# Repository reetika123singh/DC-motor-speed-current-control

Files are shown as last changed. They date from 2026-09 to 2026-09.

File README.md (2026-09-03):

# DRV8833 Dual H-Bridge Motor Driver — PCB and Cascade Speed & Current Control

A DC motor drive system built around the DRV8833 dual H-bridge driver, with a custom KiCad PCB and a Simulink/Simscape simulation of a cascade control architecture for precise speed regulation.

## Key Specifications

| Parameter | Value |
|---|---|
| Supply Voltage | 12 V |
| PWM Switching Frequency | 10 kHz |
| Speed Setpoint (simulated) | 1600 RPM |
| Current Limit (inner loop saturation) | 0 – 1.6 A |
| Control Architecture | Cascade: outer speed loop → inner current loop |

## Control Architecture

The system uses a **cascade (dual-loop) control structure**, which regulates motor speed while keeping motor current within a safe limit:

1. **Outer speed loop:**  PI controller (P = 0.002, I = 0.02) compares the RPM setpoint against measured speed and outputs a current command.
2. **Saturation stage:** The current command is clamped to 0–1.6 A, acting as a current limiter between the two loops.
3. **Inner current loop:** PI controller (P = 0.5, I = 5) compares the (limited) current command against sensed motor current and drives the H-Bridge PWM input.
4. **Plant:** An averaged H-Bridge model (12V, 10kHz) driving a Simscape DC Motor model (Ra = 2Ω, La = 1mH, Kv = 0.0072 V/rpm, J = 1e-5 kg·m²), with feedback from a Current Sensor (inner loop) and an Ideal Rotational Motion Sensor (outer loop, converted from rad/s to RPM).

## Repository Structure

- `Motor driver DRV8833.kicad_pro` (+ associated schematic/PCB files) — KiCad project for the DRV8833 driver board, including power rail decoupling and charge pump circuitry.
- `Motor_speed_control.slx` — Simulink/Simscape model implementing the cascade control loop described above.

## How to Run the Simulation

1. Open MATLAB and load `Motor_speed_control.slx` in Simulink.
2. Run the simulation to observe the motor speed settling toward the 1600 RPM setpoint and the current staying within the 0–1.6 A limit.
3. View the Scope block for speed and current response over time.

## PCB




## Results




1. **Settling time:** 0.12s
2. **Steady-state speed error:** +100 RPM
3. **Peak current during startup:** 1.4 A

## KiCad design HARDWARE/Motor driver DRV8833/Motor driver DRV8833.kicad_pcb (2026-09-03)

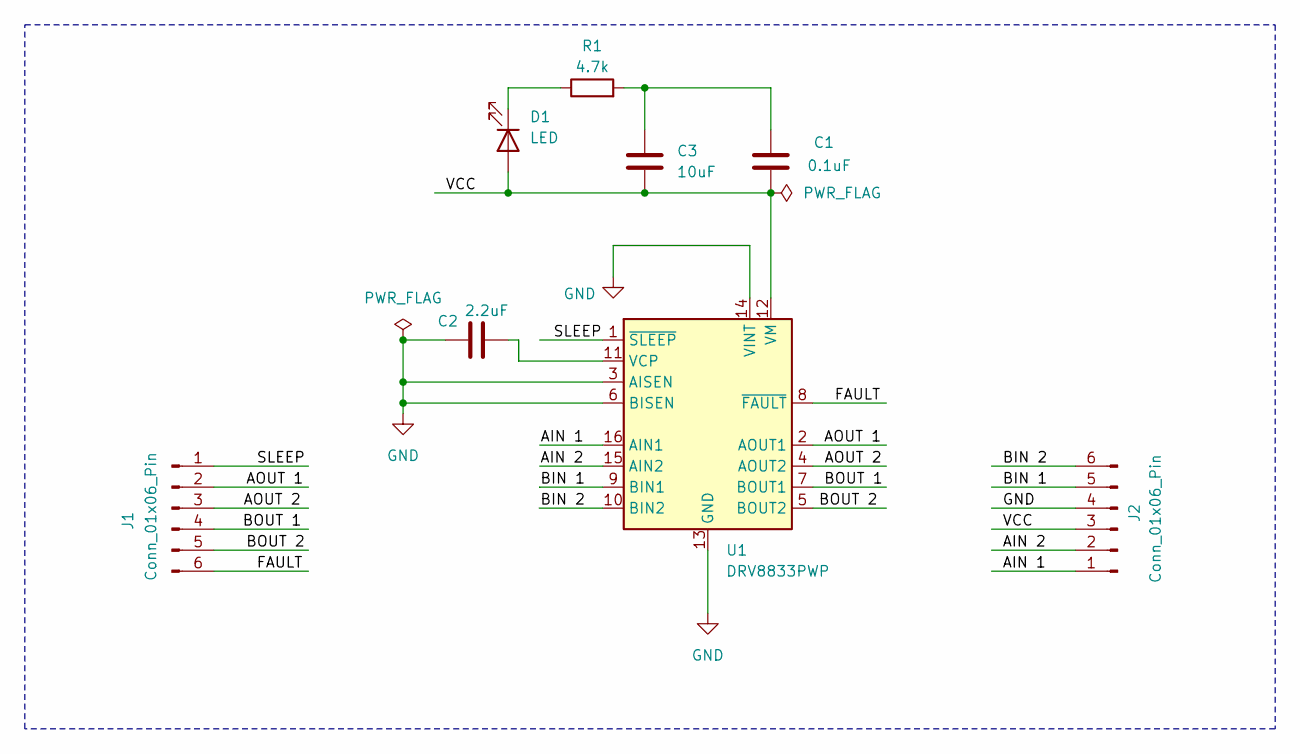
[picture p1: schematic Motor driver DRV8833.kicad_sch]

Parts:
C1: 0.1uF; C_0805_2012Metric
C2: 2.2uF; C_0805_2012Metric
C3: 10uF; CP_EIA-6032-20_AVX-F
D1: LED; LED_0805_2012Metric
J1, J2: Conn_01x06_Pin; PinHeader_1x06_P2.54mm_Vertical
R1: 4.7k; R_0805_2012Metric
U1: DRV8833PWP; HTSSOP-16-1EP_4.4x5mm_P0.65mm_EP3.4x5mm_Mask2.46x2.31mm_The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

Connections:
/AIN 1: J2.1, U1.16 (AIN1)
/AIN 2: J2.2, U1.15 (AIN2)
/AOUT 1: J1.2, U1.2 (AOUT1)
/AOUT 2: J1.3, U1.4 (AOUT2)
/BIN 1: J2.5, U1.9 (BIN1)
/BIN 2: J2.6, U1.10 (BIN2)
/BOUT 1: J1.4, U1.7 (BOUT1)
/BOUT 2: J1.5, U1.5 (BOUT2)
/FAULT: J1.6, U1.8 (~FAULT)
/SLEEP: J1.1, U1.1 (~SLEEP)
/VCC: C1.2, C3.2, D1.2 (A), J2.3, U1.12 (VM)
GND: C2.1, J2.4, U1.3 (AISEN), U1.6 (BISEN), U1.13 (GND), U1.14 (VINT), U1.17 (GND)
unnamed: C1.1, C3.1, R1.2
unnamed: D1.1 (K), R1.1
unnamed: C2.2, U1.11 (VCP)

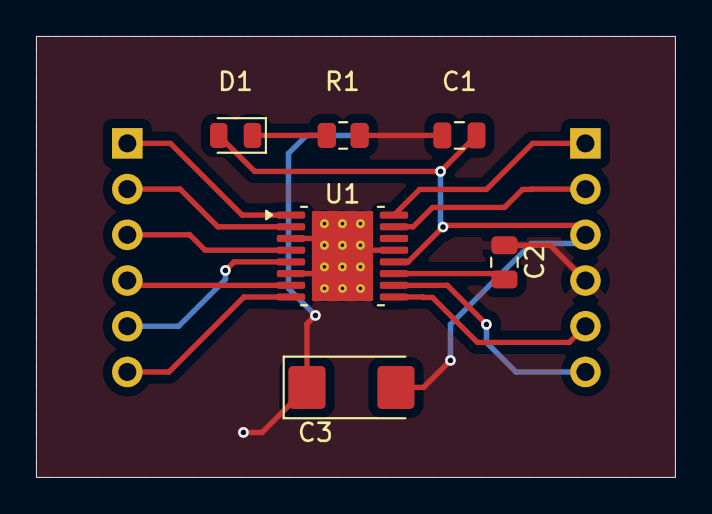
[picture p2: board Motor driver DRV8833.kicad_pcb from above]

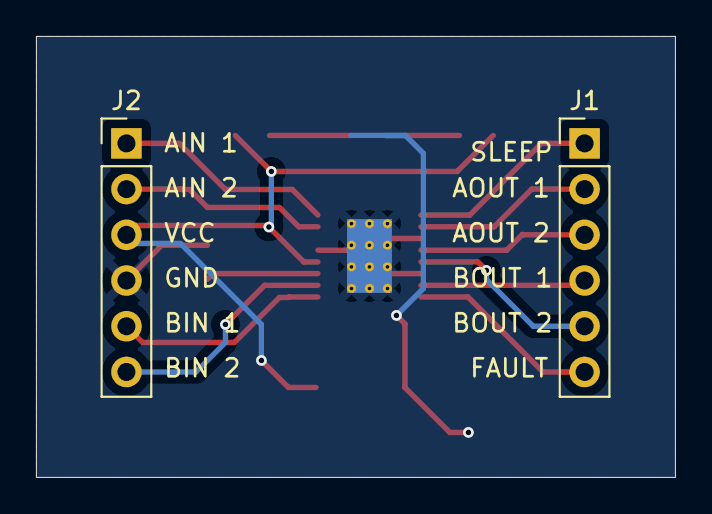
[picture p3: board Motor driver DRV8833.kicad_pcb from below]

Board: 2 copper layers, 35.5 x 24.5 mm, 8 parts (2 on the bottom side), 15 nets.
